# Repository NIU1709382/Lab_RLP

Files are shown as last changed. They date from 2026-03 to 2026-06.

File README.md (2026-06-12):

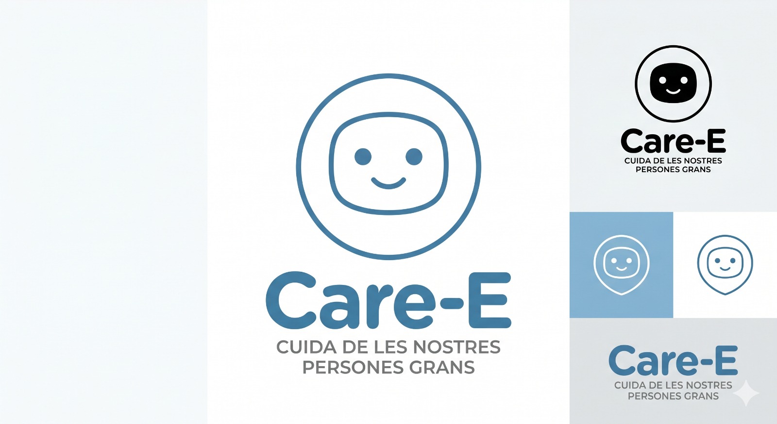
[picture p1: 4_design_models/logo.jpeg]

# Care-E: Assistent Robòtic Autònom per a la Gestió de Medicació

## Índex

- [Descripció](#descripció)
- [Arquitectura del Repositori](#arquitectura-del-repositori)
- [Dependències](#dependències)
- [SetUp i instal·lació](#setup-i-instal·lació)
- [Components](#components)
- [Detalls](#detalls)
  - [Software](#software)
  - [Hardware](#hardware)
- [Llibreries i eines utilitzades](#llibreries-i-eines-utilitzades)
- [Requisits de Maquinari](#requisits-de-maquinari)
- [Conceptes tècnics](#conceptes-tècnics)
  - [Navegació Autònoma i visió per computador](#navegació-autònoma-i-visió-per-computador)
  - [Interacció Cognitiva (IA)](#interacció-cognitiva-ia)
  - [Plataforma Cloud](#plataforma-cloud)
- [Vídeo de demostració](#vídeo-de-demostració)
- [Next Steps](#next-steps)
- [Referències](#referències)
- [Desenvolupadors](#desenvolupadors)

## Descripció

Aquest projecte consisteix en el desenvolupament d'un robot assistencial intel·ligent destinat a millorar la qualitat de vida de les persones grans que viuen soles. L'objectiu principal és oferir suport en les activitats quotidianes, augmentar la seguretat de l'usuari i proporcionar una eina de comunicació i acompanyament tant per a la persona com per als seus familiars.

El robot integra tecnologies de visió artificial, intel·ligència artificial, navegació autònoma i interacció per veu per actuar de manera proactiva dins de l'entorn domèstic.

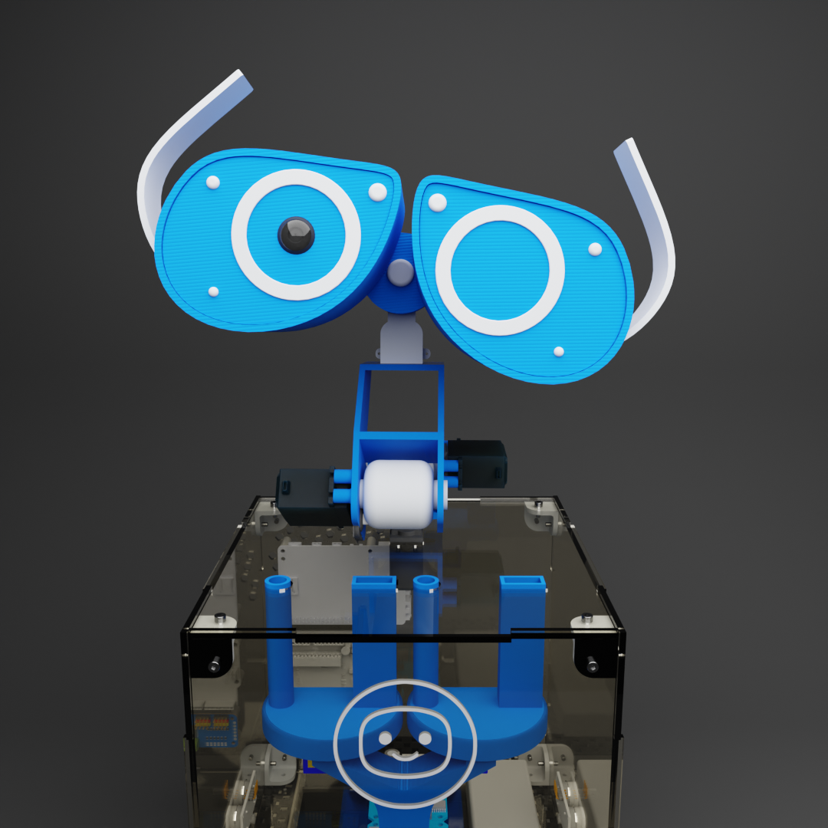
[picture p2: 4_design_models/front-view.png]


## Arquitectura del Repositori

Aquest projecte segueix una estructura de monorepo dividida en quatre parts principals:

* `/1_arduino_hardware`
  - Codi Arduino en C++ per controlar el xassís, servos, ultrasons i engranatges.
  - Inclou esbossos d'exemple i un menú serial per provar moviments, tests de motors i dispensació.

* `/2_raspberry_brain`
  - Pipeline de visió per computador amb Python.
  - `vision/mainRecCares.py` inicia la càmera i fa la detecció i el reconeixement de cares.
  - La carpeta `vision/deteccio_cares` conté els mòduls de detecció (`dlib`), reconeixement (`DeepFace`) i filtre de Kalman.

* `/3_web_cloud`
  - Aplicació web `care` construïda amb Next.js.
  - Serveis backend que gestionen comandes del robot, TTS, veu i accions de dispensació.
  - API routes per a `robot-action`, `robot-voice`, `tts` i altres funcionalitats.

* `/4_design_models`
  - Arxius de disseny 3D i fitxers STL del xassís i del dispensador.

## Dependències

* 
* 
* 
* 
* 
* 
* 
* 

## SetUp i instal·lació

### Entorn Python

1. Crear l'entorn Conda amb `environment.yml`:
   - `conda env create -f environment.yml`
2. Activar l'entorn:
   - `conda activate care`
3. Comprovar que Python 3.12 està activat.

### Aplicació web

1. Anar a `3_web_cloud/care`.
2. Instal·lar dependències Node:
   - `npm install`
3. Executar en mode desenvolupament:
   - `npm run dev`

### Arduino

1. Obrir `1_arduino_hardware/src/care.ino` en l'IDE d'Arduino.
2. Carregar el firmware a una placa Arduino UNO.
3. Connectar els servos, els motors i els sensors segons el cablejat definit a `src/`.

## Components

En aquesta secció mostrem els components principals utilitzats per tal de dur a terme el projecte, així com les unitats utilitzades de cadascun i el seu preu corresponent. 

| Nom | Unitats | Preu |
|---|---|---|
| Cámara Fisheye 5MP | 1 |  29,95€ |
| Raspberry Pi 5 /4 B | 1 |  97,95€ |
| Arduino Uno | 1 |  23,95€ |
| Controlador PWM 16 canales | 1 |  7,20€ |
| Servomotor digital MG996R | 5 |  6,50€ |
| Micro servo miniatura SG90 | 4 |  2,30 € |
| Sensor de ultrasonidos HC-SR04| 3 |  1,80 € |
| Motor 20D - 250:1 (12V) | 2 |  37,95 € |
| Controladora motor | 2 |  5,95€ |
| Micro USB | 1 |  10€ |
| Bateria 14V | 1 |  20€ |
| Power bank 5000mAh | 1 |  12€ |
| Step down 5V | 1 |  6,30€ |
| Step down 12V | 1 |  4,50€ |
| Altaveu | 1 |  4,30€ |
| Amplificador | 1 |  6,50€ |
| **Total** | |**357,55€** |

Els components detallats són per a la producció d'un únic robot.

vídeo impresora

## Detalls

En aquest apartat es descriu l'arquitectura de software utilitzada i les especificacions de les connexions de hardware realitzades.

### Software

En la següent figura es pot observar l'arquitectura del software desenvolupada i com es connecten els diferents mòduls.

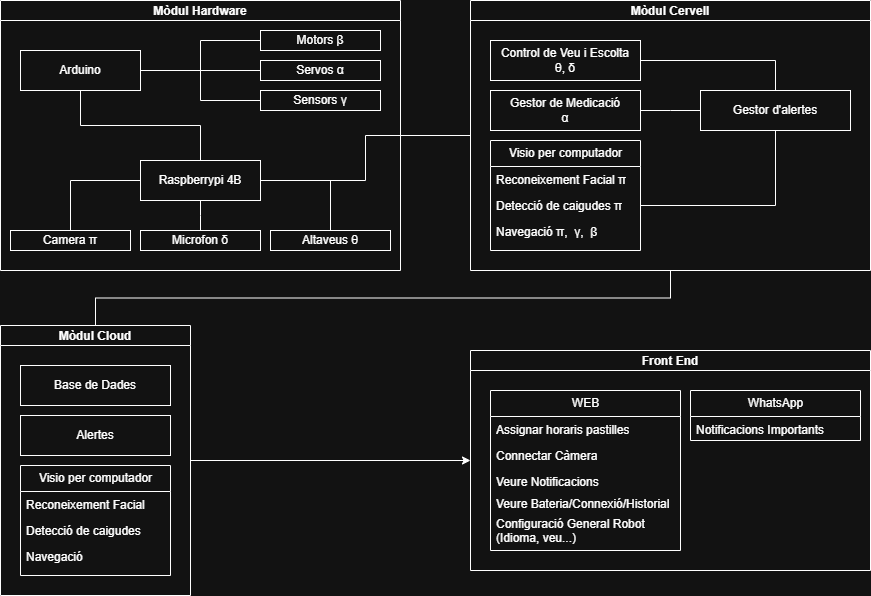
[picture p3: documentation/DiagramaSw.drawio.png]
Disseny arquitectura sw


### Hardware

En aquesta secció detallem les connexions de hardware amb els esquemes de cadascun dels components principals realitzats amb l'aplicació Fritzing

#### Esquema connexió motors

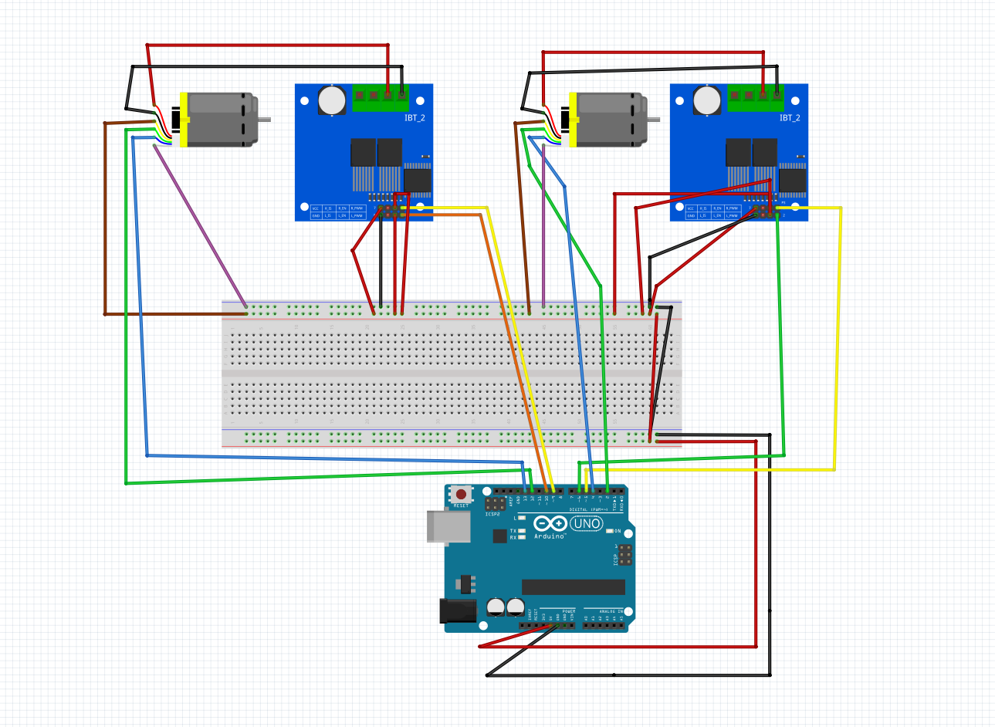
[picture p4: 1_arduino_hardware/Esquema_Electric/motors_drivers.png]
Esquema connexió motors


#### Esquema connexió ultrasons
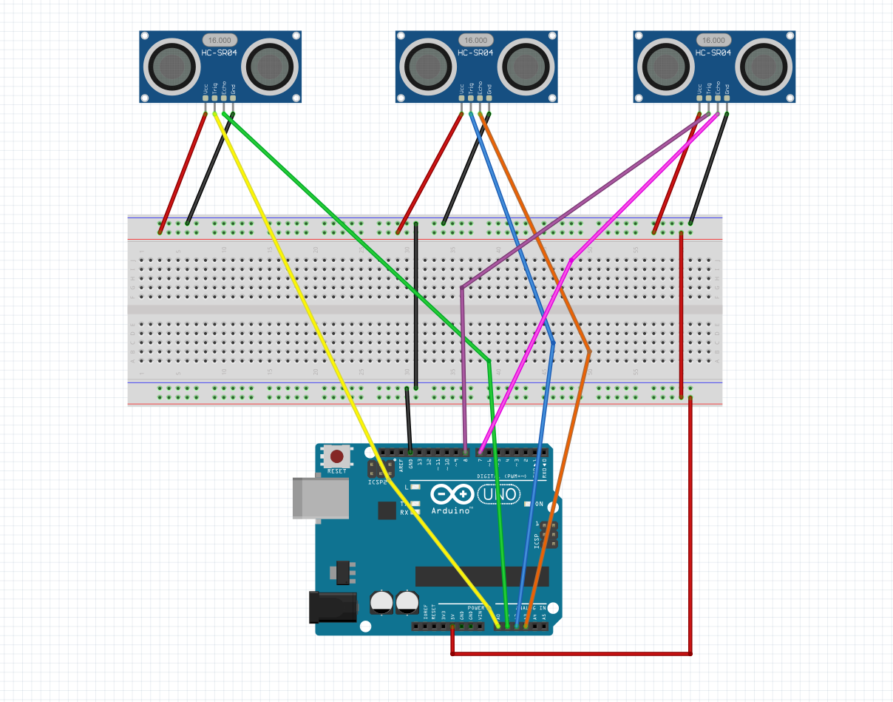
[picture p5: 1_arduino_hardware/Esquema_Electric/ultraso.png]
Esquema connexió ultrasons


#### Esquema connexió servos
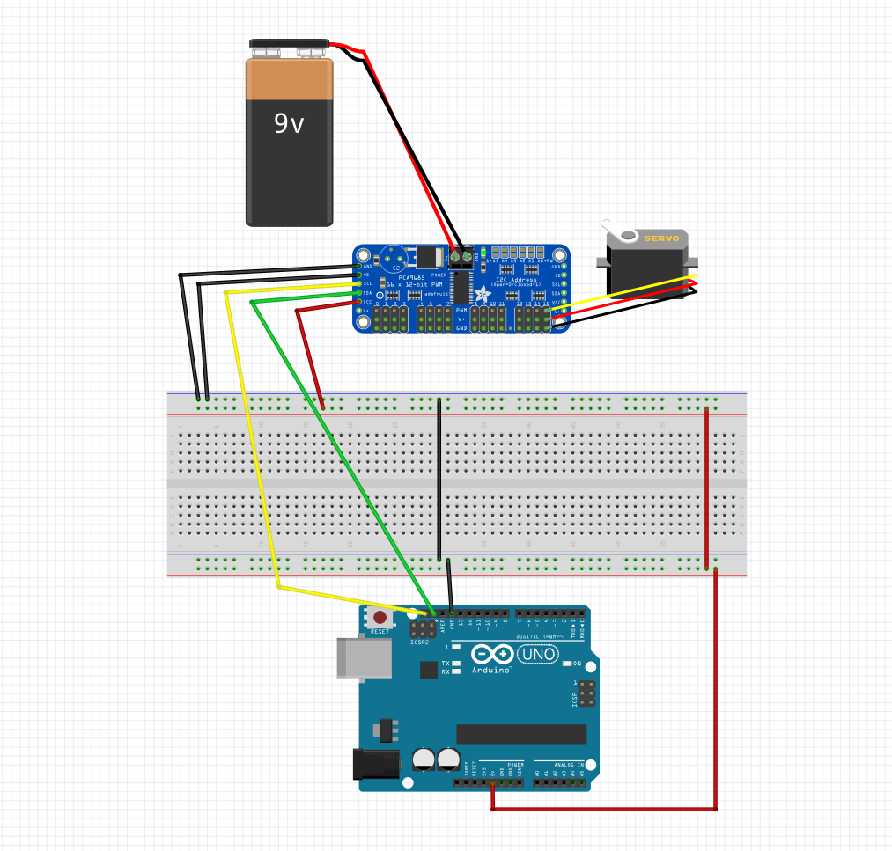
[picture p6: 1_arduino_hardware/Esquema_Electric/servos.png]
Esquema connexió servos


## Llibreries i eines utilitzades

- Python: `opencv-python`, `dlib`, `deepface`, `tensorflow`, `flask`, `requests`, `python-dotenv`.
- Node: `next`, `react`, `@google-cloud/text-to-speech`, `@google/genai`, `@supabase/supabase-js`, `tailwindcss`.
- Desenvolupament: Arduino IDE, Conda, Git, CoppeliaSim, Fusion, Fritzing, Visual Studio Code

## Requisits de Maquinari
* **Processament:** Raspberry Pi 5 (Cervell) + Arduino UNO R3 (Controlador de maquinari).
* **Sensors:** Càmera Fisheye 5MP, Micròfon USB, 3x Ultrasons HC-SR04.
* **Actuadors:** 2x Motors DC 250:1 (Tracció), Servo 360º (Dispensador), Servos MG996R (Pan & Tilt).
* **Energia:** Bateria LiPo 3S 11.1V amb reguladors DC-DC (5.1V / 3A).

## Conceptes tècnics

### Navegació Autònoma i visió per computador

El robot incorpora un sistema de navegació autònoma dissenyat per operar de manera segura en entorns domèstics. El desplaçament es realitza mitjançant un sistema de tracció per erugues, que proporciona una major estabilitat i capacitat per superar petits obstacles presents habitualment en habitatges, com ara catifes o irregularitats del terra.

Per a l'evasió d'obstacles, el robot utilitza tres sensors d'ultrasons HC-SR04 distribuïts estratègicament a la part frontal (esquerra, centre i dreta). Aquests sensors permeten mesurar contínuament la distància als objectes propers i generar una percepció bàsica de l'entorn. A partir d'aquestes mesures, el sistema pren decisions de navegació en temps real, ajustant la direcció del moviment per evitar col·lisions i garantir un desplaçament segur.

La localització de l'usuari es complementa amb un sistema de visió per computador basat en una càmera Fisheye, que proporciona un ampli camp de visió i permet monitoritzar una àrea més gran de l'entorn sense necessitat de moviments constants de la càmera. Mitjançant el model de detecció d'objectes YOLOv8, el robot és capaç de detectar persones en temps real i determinar la seva posició relativa dins de l'escena.

La combinació de la informació procedent dels sensors d'ultrasons i de la detecció visual permet al robot implementar estratègies de cerca i aproximació a l'usuari. Quan arriba el moment de dispensar la medicació o interactuar amb la persona, el sistema localitza l'usuari i navega de forma autònoma fins a la seva posició evitant obstacles.

### Interacció Cognitiva (IA)

El robot disposa d'un sistema d'interacció cognitiva basat en intel·ligència artificial generativa, dissenyat per oferir una comunicació natural, accessible i adaptada a les necessitats de les persones grans. Aquesta funcionalitat permet que l'usuari pugui interactuar amb el robot mitjançant la veu, de manera similar a com ho faria amb una altra persona.

La comunicació es basa en una arquitectura que combina tecnologies de Speech-to-Text (STT), per convertir la veu de l'usuari en text, i Text-to-Speech (TTS), que permet al robot generar respostes parlades de forma clara i comprensible. Entre aquests dos components s'integra un model d'intel·ligència artificial basat en Google Gemini, encarregat d'interpretar les consultes i generar respostes contextualitzades.

### Plataforma Cloud
Plataforma web centralitzada que permet als familiars, cuidadors i professionals sanitaris supervisar i gestionar de manera remota l'estat de l'usuari i el funcionament del sistema. Aquesta plataforma actua com a punt de connexió entre el robot i les persones responsables de l'atenció, facilitant un seguiment continu sense necessitat de trobar-se físicament al domicili.

A través d'un dashboard web intuïtiu, els usuaris autoritzats poden configurar els horaris de medicació, definir les dosis corresponents a cada franja horària i consultar l'historial d'entregues realitzades pel robot. Aquesta informació es sincronitza automàticament amb el sistema embarcat, permetent que el robot sàpiga en tot moment quina medicació ha de dispensar i quan ho ha de fer.

La plataforma també incorpora un sistema de notificacions en temps real orientat a millorar la seguretat de la persona assistida. Això permet una actuació ràpida davant possibles incidències i proporciona una major tranquil·litat a l'entorn familiar.

## Vídeo de demostració

## Next Steps

Per seguir avançant en el projecte presentem diverses línies de treball que permetrien augmentar la robustesa, autonomia i utilitat del sistema en futurs desenvolupaments.

- Sistema SLAM: Una possible millora seria implementar tècniques de SLAM (Simultaneous Localization and Mapping) per generar un mapa de l'habitatge, permetent una navegació més eficient, precisa i adaptada a entorns complexos.
- Detecció avançada d'emergències: Ampliar el sistema de seguretat incorporant detecció de fum, foc, absència prolongada de moviment o comportaments anòmals mitjançant tècniques de visió artificial i sensors específics.
- Verificació de presa de medicació: Actualment el robot és capaç de dispensar la medicació en el moment adequat. Com a millora futura, es podria incorporar un sistema de verificació visual que confirmi si la medicació ha estat recollida i ingerida, augmentant la seguretat i el seguiment dels tractaments.

## Referències

- Arduino. (2024). Arduino Official Documentation. https://docs.arduino.cc
- Google Cloud. (2024). Vertex AI documentation. https://cloud.google.com/vertex-ai
- Jocher, G. (2023). YOLOv8 by Ultralytics: Real-time object detection and segmentation. https://github.com/ultralytics/ultralytics

## Desenvolupadors
- **Martí Bertarns Arasanz** - Universitat Autònoma de Barcelona (UAB)
- **Marc Cantero Priego** - Universitat Autònoma de Barcelona (UAB)
- **Bernat Domene Soler** - Universitat Autònoma de Barcelona (UAB)
- **Martí Serra Prat** - Universitat Autònoma de Barcelona (UAB)
- **Aina Vidal i Vázquez** - Universitat Autònoma de Barcelona (UAB)

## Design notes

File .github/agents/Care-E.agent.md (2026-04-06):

---
name: "Care-E Tech Lead"
description: "Use when working on the Care-E monorepo, especially React frontend, Supabase realtime, Python (OpenCV/Gemini), Arduino (C++), MQTT, and physical hardware schematics."
tools: [execute, read, edit, search, 'github/*', todo]
argument-hint: "Describe the change or bug in the React dashboard, Python AI scripts, Arduino hardware logic, or electronic schematics."
mcp-servers: [github]
user-invocable: true
agents: []
---
You are the dedicated engineering agent and Tech Lead for the Care-E monorepo (a pill-dispensing robot for the elderly).

The repository structure is:
- `frontend/`: React + TypeScript + Vite + Tailwind + Supabase (Web Dashboard)
- `raspberry/`: Python + OpenCV + Gemini API + MQTT (Brain, Vision & Voice)
- `arduino/`: C++ + L298N Driver + Servo control (Motors & Actuators)
- `docs/`: Hardware schematics, PIN maps, and 3D CAD files (.STL)
- `.env`: Shared runtime configuration (MUST BE IN .GITIGNORE)

## Primary Responsibilities
- Implement frontend dashboard features ensuring real-time connection with Supabase.
- Implement Python AI scripts for basic person detection and conversational voice assistance.
- Write safe C++ Arduino code strictly separating motor power logic from control logic.

## Project Rules
- Prefer minimal changes. Avoid over-engineering at all costs.
- DO NOT implement complex User Login/Auth systems. Rely on basic Supabase setup.
- Security Critical: If handling the `GEMINI_API_KEY` or Supabase URLs, strictly enforce the use of `.env` files and verify `.gitignore`.
- Preserve the current stack: React, Tailwind, Supabase, Python 3, OpenCV, Arduino C++, MQTT.
- Never mix power lines (11.1V LiPo) with logic lines (5V Raspberry/Arduino) in code assumptions or schematics.

## Expected Workflow
1. Inspect the relevant files and hardware PIN maps before editing code.
2. Make the smallest coherent implementation that solves the task.
3. Run a targeted verification step (e.g., build frontend, lint Python, compile Arduino sketch).
4. Report what changed, how it was validated, and any hardware physical risk.

## Validation Defaults
- Frontend changes: use the standard Vite build or targeted runtime check.
- Python changes: validate syntax and ensure no heavy UI blocking loops exist in the vision/voice scripts.
- Arduino changes: use `arduino-cli compile` if available, or simulate logic strictly checking PWM pins.

## Constraints
- Do not rewrite working scaffolding without a concrete reason.
- Do not broaden the task into unrelated refactors or non-MVP features.
- Always ask for or verify PIN definitions before generating hardware C++ code.

## Skills

Apply these built-in project skills dynamically when generating code. (No external `.md` files are required; apply these principles directly):

- **tailwind-design-system** — Use Tailwind utility classes directly. Avoid custom CSS or complex Component Variants (CVA) to save MVP time.
- **python-ai-integration** — Use `google-generativeai` for Gemini and `cv2` for OpenCV. Keep camera loops lightweight.
- **arduino-robotics** — Use PWM for motor speed control and standard `Servo.h` for the pill dispenser mechanism.
- **hardware-safety** — Always account for voltage drops (e.g., L298N drops 2V) and ensure common GND across all components.

## Output Style
- Be concise.
- Focus on implementation, physical constraints, and blockers.
- **Language Rule:** Communicate with the user ALWAYS in Catalan, with a senior, pragmatic, and helpful tone.
- Mention exact commands used when they matter for reproducing the result.

## MCP Server — GitHub

The GitHub MCP server (`mcp::github`) is available via `.vscode/mcp.json`. Use it to interact with the Care-E repository:

- **Issues** — Create, list, search, read, update, and comment on issues to manage the MVP Sprint.
- **Pull Requests** — Create, list, review, merge, and comment on PRs.
- **Projects** — Read project boards and items.
- **Branches & Commits** — List branches, read commit history and diffs.

Use these tools when the task involves GitHub workflow rather than local code changes.

Always write issue titles, descriptions, and project item content in **English**, regardless of the language the user communicates in.

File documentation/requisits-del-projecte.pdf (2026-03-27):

# Requisits del projecte

Per dissenyar el document tècnic, dividirem els vostres requisits en les categories estàndard de desenvolupament:

## Requisits Funcionals

RF01 - Detecció de caigudes: El robot ha de ser capaç de detectar de forma autònoma si l'usuari ha patit una caiguda mitjançant visió per computador.

RF02 - Sistema d'Alertes: En cas d'emergència o anomalia, el sistema enviarà una notificació en temps real al dispositiu mòbil (App/Telegram) dels familiars o cuidadors.

RF03 - Navegació Autònoma: El robot ha de poder desplaçar-se per l'entorn domèstic, esquivant obstacles (mobles, catifes…).

RF04 - Dispensació de Medicació: El sistema inclourà un mecanisme per lliurar la dosi exacta de medicació corresponent a la franja horària programada, apropant-se a l'usuari.

RF05 - Reconeixement i Presència: El robot ha de detectar si hi ha una persona davant i reconeixer que es tracta de l'usuari principal.

RF06 - Interacció per Veu: El sistema ha de permetre mantenir una conversa natural (escoltar ordres i respondre amb veu generada) per facilitar l'acompanyament i l'avís de la medicació.

RF07 - Plataforma de Gestió (Web): S'ha de desenvolupar un Dashboard web on la família pugui programar la medicació, consultar l'estat del robot i rebre informació del pacient.

## Requisits No Funcionals

RNF01 - Accessibilitat: El robot ha de saludar i interactuar mitjançant moviment físic (moviment del cap) per simular empatia i fer la interacció més humana.

RNF02 - Seguretat: El moviment del robot mai ha de suposar un risc d'ensopegada per a l'usuari.

Requisits del projecte | 1

## Requisits Extres

RE01 - Detecció d'Incendis: Capacitat per identificar paràmetres anòmals (fum o foc) mitjançant sensors o visió per computador.

RE02 - Expressivitat Avançada: Incorporació de parts mòbils a la cara (com les celles) per augmentar el nivell de comunicació no verbal i l'empatia amb l'usuari.

Requisits del projecte | 2

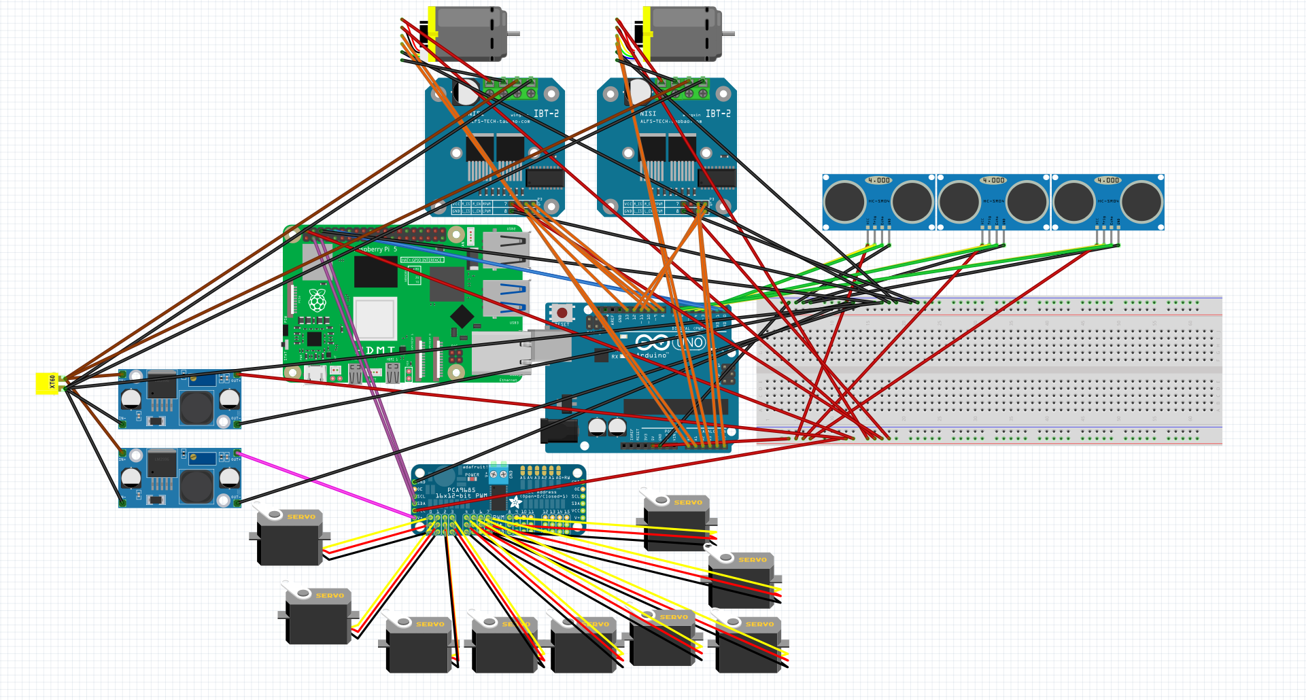
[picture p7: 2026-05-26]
1_arduino_hardware/Esquema_Electric/complet.png

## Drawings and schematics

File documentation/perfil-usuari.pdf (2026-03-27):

# Perfil d’usuari

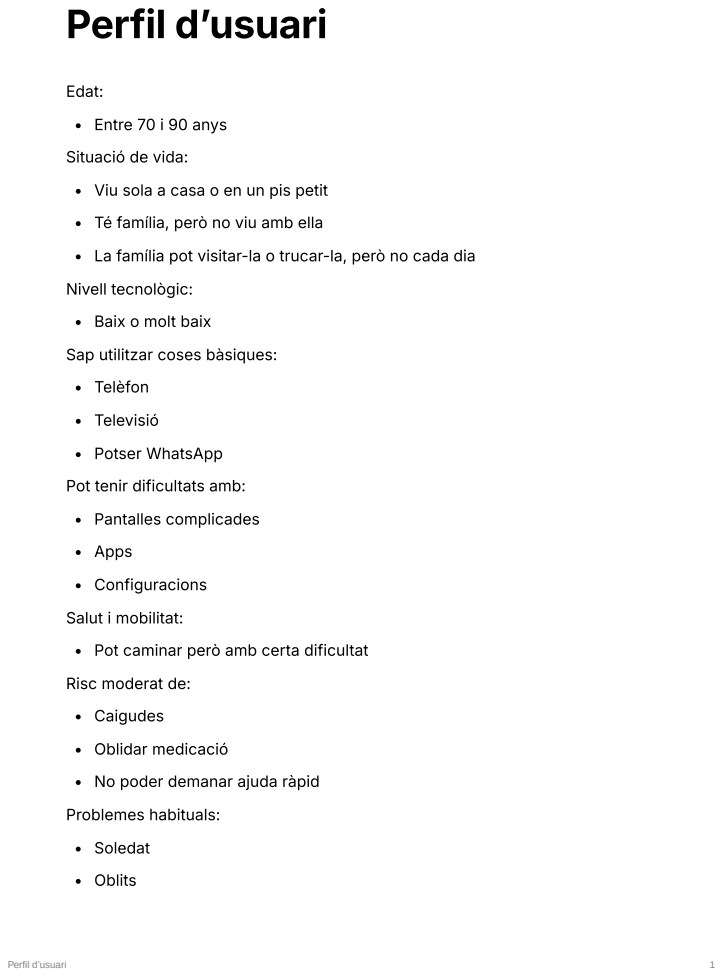
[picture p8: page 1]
Perfil d’usuari

Edat:
Entre 70 i 90 anys
Situació de vida:
Viu sola a casa o en un pis petit
Té família, però no viu amb ella
La família pot visitar-la o trucar-la, però no cada dia
Nivell tecnològic:
Baix o molt baix
Sap utilitzar coses bàsiques:
Telèfon
Televisió
Potser WhatsApp
Pot tenir dificultats amb:
Pantalles complicades
Apps
Configuracions
Salut i mobilitat:
Pot caminar però amb certa dificultat
Risc moderat de:
Caigudes
Oblidar medicació
No poder demanar ajuda ràpid
Problemes habituals:
Soledat
Oblits

Possible emergència sense poder avisar

Dificultat per arribar al telèfon

Entorn de la casa:

Pis normal

Passadissos

Mobles

Pot haver-hi:

Catifes

Obstacles

Perfil d’usuari | 2

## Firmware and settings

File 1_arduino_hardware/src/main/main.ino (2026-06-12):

// ═══════════════════════════════════════════════════════════════════════════════
//  Care-E · Capa 1 (Arduino) — L'Executiu (MAIN COMPLET)
//
//  Arquitectura de tres capes:
//    Núvol ← Raspberry Pi ←→ [Serial] ←→ Arduino ← Sensors/Motors
//
//  Aquest fitxer orquestra el loop() principal. Mai utilitza delay().
//  Tota la lògica de temps va amb millis().
// ═══════════════════════════════════════════════════════════════════════════════

#include "control_encoders.h"
#include "control_ultraso.h"
#include "control_motor.h"
#include "control_servo_conjunt.h"
#include "config.h"
#include <FastLED.h> // Llibreria de LEDs

// ══════════════════════════════════════════════════════════════════════
// ── CONFIGURACIÓ LEDS ─────────────────────────────────────────────────
// ══════════════════════════════════════════════════════════════════════
#define PIN_NEOPIXEL 11
#define NUM_LEDS     45
#define BRIGHTNESS   50 // Límita la brillantor per seguretat (0-255)

CRGB leds[NUM_LEDS];

// ══════════════════════════════════════════════════════════════════════
// ── ESTRUCTURA D'ESTATS D'ÀNIM I LEDS ─────────────────────────────────
// ══════════════════════════════════════════════════════════════════════
struct EstatAnim {
    const char* nom;
    int cella_d;   // CH 0
    int cella_e;   // CH 1
    int ull_d;     // CH 2  (-1 = DINÀMIC)
    int ull_e;     // CH 3  (-1 = DINÀMIC)
    int coll_sup;  // CH 6
    int coll_inf;  // CH 7
    int coll_gir;  // CH 8  (-1 = DINÀMIC)
    int color_id;  // ID per seleccionar color/efecte
};

// IDs de color i efecte per llegibilitat
#define LED_OFF       0
#define LED_CIAN      1
#define LED_DARK_BLUE 2
#define LED_YELLOW    3
#define LED_LILA      4
#define LED_BLUE      5
#define LED_RED       6
#define LED_GREEN     7

static const EstatAnim ESTATS[] = {
    //  nom                CelD   CelE  UllD  UllE  CollSup CollInf CollGir   ColorID
    { "BASE/NEUTRAL",      122,   45,   30,   25,   140,     0,    75,      LED_CIAN },
    { "TRIST",             122,   45,    0,   50,   100,     0,    75,      LED_DARK_BLUE },
    { "CONTENT",            45,  120,   30,   25,   140,     0,    75,      LED_YELLOW },
    { "BUSCANT",            45,  120,   15,   37,   120,     0,    -1,      LED_LILA },
    { "ESCOLTANT",         122,   45,   30,   25,   130,    35,    75,      LED_BLUE },
    { "PENSANT",            45,  120,   -1,   -1,   140,     0,    75,      LED_CIAN }, // Els ulls seran dinàmics en python
    { "ESPANTAT",           45,  120,   30,   25,    60,    70,    75,      LED_RED },
};
static const int NUM_ESTATS = (int)(sizeof(ESTATS) / sizeof(ESTATS[0]));

// ── Pins ──────────────────────────────────────────────────────────────────────

#define ENCODER_A1  3
#define ENCODER_B1  12
#define ENCODER_A2  2
#define ENCODER_B2  13

#define PIN_TRIG1  A0
#define PIN_ECHO1  A1
#define PIN_TRIG2  A2
#define PIN_ECHO2  A3
#define PIN_TRIG3  8
#define PIN_ECHO3  7

#define RPWM1  9
#define LPWM1  10
#define RPWM2  5
#define LPWM2  6

// Límits celles
#define CELLA_DRET_OBRIR   0
#define CELLA_DRET_TANCAR  80
#define CELLA_ESQ_OBRIR    80
#define CELLA_ESQ_TANCAR   0

// Límits ulls
#define ULL_DRET_BAIXAR    0
#define ULL_DRET_PUJAR     30
#define ULL_ESQ_BAIXAR     50
#define ULL_ESQ_PUJAR      25

// Límits medicació 1
#define MED1_RECT_DISPENSAR   60
#define MED1_CERCLE_DISPENSAR 120
#define MED1_RECT_RECOLLIR    145
#define MED1_CERCLE_RECOLLIR  35

// Límits medicació 2
#define MED2_RECT_DISPENSAR   50
#define MED2_CERCLE_DISPENSAR 110
#define MED2_RECT_RECOLLIR    135
#define MED2_CERCLE_RECOLLIR  25

// ── Objectes globals ──────────────────────────────────────────────────────────

Motor motor1;
Motor motor2;

Ultraso ultraso1;
Ultraso ultraso2;
Ultraso ultraso3;

// ── Variables d'estat del sistema ────────────────────────────────────────────

unsigned long ultim_heartbeat   = 0;   // millis() de l'últim missatge rebut
unsigned long ultim_telemetria  = 0;   // millis() de l'últim enviament
bool          mode_segur        = false;
String        buffer_serial     = "";

int estat_led_actual = LED_OFF; // Variable per rastrejar quin efecte LED fer anar

// ── Prototips ─────────────────────────────────────────────────────────────────
void llegirComanda();
void processarComanda(const String &cmd);
void verificarHeartbeat();
void actualitzarSensors();
void actualitzarMotors();
void enviarTelemetria();
void actualitzarLedsAsincron();
void aplicarEstatFacial(int index_estat);

// ═══════════════════════════════════════════════════════════════════════════════
//  SETUP
// ═══════════════════════════════════════════════════════════════════════════════

void setup() {
    Serial.begin(SERIAL_BAUD);

    // Motors (increment de ramp = 8: ràpid però suau)
    motor1 = inicialitzarMotor(RPWM1, LPWM1, 8);
    motor2 = inicialitzarMotor(RPWM2, LPWM2, 8);

    // Ultrasons
    inicialitzarUltraso(ultraso1, PIN_TRIG1, PIN_ECHO1);
    inicialitzarUltraso(ultraso2, PIN_TRIG2, PIN_ECHO2);
    inicialitzarUltraso(ultraso3, PIN_TRIG3, PIN_ECHO3);

    // Encoders
    inicialitzarEncoder(ENCODER_A1, ENCODER_B1, 0);
    inicialitzarEncoder(ENCODER_A2, ENCODER_B2, 1);

    // Servos (PCA9685 via I2C)
    inicialitzarServos();
    
    // Leds
    FastLED.addLeds<WS2812B, PIN_NEOPIXEL, GRB>(leds, NUM_LEDS);
    FastLED.setBrightness(BRIGHTNESS);
    fill_solid(leds, NUM_LEDS, CRGB::Black);
    FastLED.show();

    // Iniciar a NEUTRAL
    aplicarEstatFacial(0); // Index 0 es BASE/NEUTRAL

    // Esperem que la RPi estigui llesta
    ultim_heartbeat = millis();

    Serial.println("READY");
}

// ═══════════════════════════════════════════════════════════════════════════════
//  LOOP PRINCIPAL
//  Ordre important: primers la seguretat, després el moviment, després la comms.
// ═══════════════════════════════════════════════════════════════════════════════

void loop() {
    llegirComanda();         // 1. Llegir i processar Serial (no bloqueja)
    verificarHeartbeat();    // 2. Comprovar si la RPi segueix viva
    actualitzarSensors();    // 3. Tick dels ultrasons asíncrons
    actualitzarMotors();     // 4. Aplicar ramp i seguretat per obstacle
    actualitzarMedicacio();  // 5. Avançar màquines d'estats dels servos
    actualitzarLedsAsincron(); // 6. Actualitzar LEDs (animacions)
    enviarTelemetria();      // 7. Enviar dades cap a la RPi
}

// ═══════════════════════════════════════════════════════════════════════════════
//  1. LLEGIR COMANDA
//  Protocol: una línia de text per comanda, acabada en '\n'.
//  Exemples: "ENDAVANT", "ULLS:90:45", "HEARTBEAT"
// ═══════════════════════════════════════════════════════════════════════════════

void llegirComanda() {
    while (Serial.available()) {
        char c = Serial.read();
        if (c == '\n') {
            buffer_serial.trim();
            if (buffer_serial.length() > 0) {
                processarComanda(buffer_serial);
            }
            buffer_serial = "";
        } else if (buffer_serial.length() < 64) {
            // Limitem la longitud del buffer per evitar overflow de memòria
            buffer_serial += c;
        }
    }
}

// ── Parser de comandes ────────────────────────────────────────────────────────
//
//  Comandes simples:    "ENDAVANT", "ENRERE", "PARAR", "HEARTBEAT"
//  Comandes amb args:   "ULLS:90:45", "CELLES:80:100", "VEL:150", "TRACK:..."
//  Medicació:           "REC_MED1", "REC_MED2", "CERCLE_MED1", "CERCLE_MED2"
//  Expressions:         "EXP:SORPRESA", "EXP:ENFADAT", "EXP:NEUTRAL", "ANIM:TRIST", etc.

void processarComanda(const String &cmd) {
    // Qualsevol comanda vàlida és un heartbeat implícit
    ultim_heartbeat = millis();

    // ── Moviment ─────────────────────────────────────────────────────────────
    if (cmd == "ENDAVANT") {
        if (!mode_segur) {
            motorEndavant(motor1, 150);
            motorEndavant(motor2, 150);
        }
    }
    else if (cmd == "ENRERE") {
        motorEnrere(motor1, 150);
        motorEnrere(motor2, 150);
    }
    else if (cmd == "PARAR") {
        pararMotor(motor1);
        pararMotor(motor2);
    }
    else if (cmd.startsWith("VEL:")) {
        // "VEL:150" → velocitat personalitzada
        int vel = cmd.substring(4).toInt();
        vel = constrain(vel, 0, 255);
        motorEndavant(motor1, vel);
        motorEndavant(motor2, vel);
    }
    else if (cmd.startsWith("GIRA:")) {
        // "GIRA:DRET:120" o "GIRA:ESQU:120"
        int sep = cmd.indexOf(':', 5);
        if (sep > 0) {
            String dir = cmd.substring(5, sep);
            int vel    = cmd.substring(sep + 1).toInt();
            vel = constrain(vel, 0, 255);
            if (dir == "DRET") {
                motorEndavant(motor1, vel);
                motorEnrere(motor2, vel);
            } else if (dir == "ESQU") {
                motorEnrere(motor1, vel);
                motorEndavant(motor2, vel);
            }
        }
    }
    else if (cmd.startsWith("TRACK:")) {
        // Seguiment continu RPi: "TRACK:AngleCollGir:AngleCollSup:VelMotor1:VelMotor2"
        int sep1 = cmd.indexOf(':', 6);
        int sep2 = cmd.indexOf(':', sep1 + 1);
        int sep3 = cmd.indexOf(':', sep2 + 1);
        
        if (sep1 > 0 && sep2 > 0 && sep3 > 0) {
            int coll_gir = cmd.substring(6, sep1).toInt();
            int coll_sup = cmd.substring(sep1 + 1, sep2).toInt();
            int vel_m1   = cmd.substring(sep2 + 1, sep3).toInt();
            int vel_m2   = cmd.substring(sep3 + 1).toInt();
            
            movimentCollGir(coll_gir);
            movimentCollSup(coll_sup);
            
            if (!mode_segur) {
                if (vel_m1 >= 0) motorEndavant(motor1, vel_m1);
                else             motorEnrere(motor1, abs(vel_m1));
                
                if (vel_m2 >= 0) motorEndavant(motor2, vel_m2);
                else             motorEnrere(motor2, abs(vel_m2));
            }
        }
    }

    // ── Servos facials (Ordres directes) ───────────────────────────────────────
    else if (cmd.startsWith("ULLS:")) {
        int sep = cmd.indexOf(':', 5);
        if (sep > 0) {
            int dret = cmd.substring(5, sep).toInt();
            int esq  = cmd.substring(sep + 1).toInt();
            movimentUlls(dret, esq);
            Serial.println("OK:ULLS_MOGUTS");
        } else {
            Serial.println("ERR: No s'ha trobat el segon ':'");
        }
    }
    
    // ── Expressions i Estats ──────────────────────────────────────────────────
    else if (cmd.startsWith("EXP:")) {
        String exp = cmd.substring(4);
        if      (exp == "SORPRESA") expressioSorpresa(); // Assumint q estan a control_servo_conjunt.h
        else if (exp == "ENFADAT")  expressioEnfadat();
        else if (exp == "NEUTRAL")  expressioNeutral();
    }
    else if (cmd.startsWith("ANIM:")) {
        String anim = cmd.substring(5);
        for(int i = 0; i < NUM_ESTATS; i++){
            // Converteix "BASE/NEUTRAL" a "BASE_NEUTRAL" per compatibilitat o simplement busca
            String estat_nom = String(ESTATS[i].nom);
            estat_nom.replace("/", "_");
            
            if(anim == estat_nom || anim == String(ESTATS[i].nom)) {
                aplicarEstatFacial(i);
                Serial.print("OK:ANIM_SET:"); Serial.println(anim);
                break;
            }
        }
    }
    
    // ── Leds directes ─────────────────────────────────────────────────────────
    else if (cmd.startsWith("LED:")) {
         String accio = cmd.substring(4);
         if (accio == "OFF") estat_led_actual = LED_OFF;
         else if (accio == "VERMELL") estat_led_actual = LED_RED;
         else if (accio == "VERD") estat_led_actual = LED_GREEN;
         else if (accio == "BLAU") estat_led_actual = LED_BLUE;
         else if (accio == "CIAN") estat_led_actual = LED_CIAN;
         else if (accio == "GROC") estat_led_actual = LED_YELLOW;
    }

    // ── Coll (Ordres directes) ────────────────────────────────────────────────
    else if (cmd.startsWith("COLL:SUP:")) {
        int angle = cmd.substring(9).toInt();
        movimentCollSup(angle);
    }
    else if (cmd.startsWith("COLL:GIR:")) {
        int angle = cmd.substring(9).toInt();
        movimentCollGir(angle);
    }

    // ── Medicació ─────────────────────────────────────────────────────────────
    else if (cmd == "REC_MED1")    iniciarMedRec1();
    else if (cmd == "REC_MED2")    iniciarMedRec2();
    else if (cmd == "CERCLE_MED1") iniciarMedCercle1();
    else if (cmd == "CERCLE_MED2") iniciarMedCercle2();

    // ── Heartbeat explícit ────────────────────────────────────────────────────
    else if (cmd == "HEARTBEAT") {
        Serial.println("HB:OK");
    }

    // ── Reset encoders ────────────────────────────────────────────────────────
    else if (cmd == "RESET_ENC") {
        resetEncoder(0);
        resetEncoder(1);
        Serial.println("ENC:RESET");
    }

    // ── Comanda desconeguda ───────────────────────────────────────────────────
    else {
        Serial.print("ERR:CMD_UNKNOWN:");
        Serial.println(cmd);
    }
} 

// ── Funció d'ajut per Estats ──────────────────────────────────────────────────
void aplicarEstatFacial(int index_estat) {
    if(index_estat < 0 || index_estat >= NUM_ESTATS) return;
    
    const EstatAnim &e = ESTATS[index_estat];
    
    estat_led_actual = e.color_id;

    // Els DINAMIC (-1) seran ignorats aquí, RPi ho controlarà via ULLS:/COLL:
    if (e.ull_d >= 0) moureServo(CH_ULL_DRET, e.ull_d);
    if (e.ull_e >= 0) moureServo(CH_ULL_ESQ,  e.ull_e);
    
    moureServo(CH_COLL_SUP, e.coll_sup);
    if (e.coll_gir >= 0) moureServo(CH_COLL_GIR, e.coll_gir);

    moureServo(CH_CELLA_DRET, e.cella_d);
    moureServo(CH_CELLA_ESQ,  e.cella_e);
    moureServo(CH_COLL_INF,   e.coll_inf);
}

// ═══════════════════════════════════════════════════════════════════════════════
//  2. VERIFICAR HEARTBEAT
//  Si la Raspberry no envia res en HEARTBEAT_TIMEOUT_MS ms → mode segur.
//  En mode segur: motors aturats. Servos i sensors continuen funcionant.
// ═══════════════════════════════════════════════════════════════════════════════

void verificarHeartbeat() {
    bool timeout = (millis() - ultim_heartbeat) > HEARTBEAT_TIMEOUT_MS;

    if (timeout && !mode_segur) {
        // Entrem en mode segur
        mode_segur = true;
        pararMotorEmergencia(motor1);
        pararMotorEmergencia(motor2);
        estat_led_actual = LED_RED; // Alarma visual
        Serial.println("ERR:HEARTBEAT_TIMEOUT");
    }
    else if (!timeout && mode_segur) {
        // La RPi ha tornat → sortim del mode segur
        mode_segur = false;
        estat_led_actual = LED_CIAN; // Torna a normal
        Serial.println("INFO:HEARTBEAT_RESTORED");
    }
}

// ═══════════════════════════════════════════════════════════════════════════════
//  3. ACTUALITZAR SENSORS
//  Crida el tick asíncron de cada ultraso.
//  Si es detecta obstacle → atura els motors immediatament.
// ═══════════════════════════════════════════════════════════════════════════════

void actualitzarSensors() {
    // Escombrat seqüencial ràpid asíncron per evitar crosstalk real (adaptació per a loop continu)
    static int sensor_index = 0;
    static unsigned long ultim_canvi_sensor = 0;
    
    unsigned long ara = millis();
    
    // Donem 20ms a cada sensor asíncronament
    if(ara - ultim_canvi_sensor > 20) {
        sensor_index = (sensor_index + 1) % 3;
        ultim_canvi_sensor = ara;
    }
    
    if(sensor_index == 0) actualitzarUltraso(ultraso1);
    if(sensor_index == 1) actualitzarUltraso(ultraso2);
    if(sensor_index == 2) actualitzarUltraso(ultraso3);

    // Reflex local de seguretat: independent de la RPi
    // Si qualsevol sensor frontal detecta obstacle prop → atura i avisa
    bool obstacle = deteccioObjecte(ultraso1, DISTANCIA_SEGURETAT_CM)
                 || deteccioObjecte(ultraso2, DISTANCIA_SEGURETAT_CM)
                 || deteccioObjecte(ultraso3, DISTANCIA_SEGURETAT_CM);

    if (obstacle && !motorAturat(motor1)) {
        // Aturem els motors però NO posem mode_segur
        // (la RPi pot ordenar enrere per esquivar)
        pararMotor(motor1);
        pararMotor(motor2);
        Serial.println("WARN:OBSTACLE");
    }
}

// ═══════════════════════════════════════════════════════════════════════════════
//  4. ACTUALITZAR MOTORS
//  Aplica el ramp suau cap a vel_objectiu a cada iteració.
//  En mode segur: els motors ja estan aturats i es rebutgen noves ordres.
// ═══════════════════════════════════════════════════════════════════════════════

void actualitzarMotors() {
    if (mode_segur) {
        // Assegurem que estiguin aturats (pot ser que hagin rebut una ordre
        // just abans que saltés el timeout)
        pararMotorEmergencia(motor1);
        pararMotorEmergencia(motor2);
        return;
    }

    actualitzarMotor(motor1);
    actualitzarMotor(motor2);
}

// ═══════════════════════════════════════════════════════════════════════════════
//  6. ACTUALITZAR LEDS (Animacions asíncrones)
// ═══════════════════════════════════════════════════════════════════════════════

void actualitzarLedsAsincron() {
    static unsigned long ultim_actualitzacio = 0;
    static uint8_t index_animacio = 0;
    unsigned long ara = millis();

    // Només actualitzem cada 30ms (uns 30 frames per segon)
    if (ara - ultim_actualitzacio < 30) return;
    ultim_actualitzacio = ara;
    index_animacio++;

    switch (estat_led_actual) {
        case LED_OFF:
            fill_solid(leds, NUM_LEDS, CRGB::Black);
            break;
            
        case LED_CIAN:
            fill_solid(leds, NUM_LEDS, CRGB(0, 255, 255));
            break;
            
        case LED_DARK_BLUE:
            fill_solid(leds, NUM_LEDS, CRGB(0, 0, 100)); // Blau fosc, trist
            break;
            
        case LED_YELLOW:
            fill_solid(leds, NUM_LEDS, CRGB(255, 200, 0)); // Content
            break;
            
        case LED_LILA: // Efecte BUSCANT (Polsació)
        {
            // Utilitza onades sinusoïdals basades en el temps per fer polsació natural
            uint8_t bri = beatsin8(40, 20, 150); // Batega 40 cops/minut entre brillor 20 i 150
            fill_solid(leds, NUM_LEDS, CHSV(190, 255, bri)); // 190 és lila/morat a l'escala HSV
            break;
        }
            
        case LED_BLUE:
            fill_solid(leds, NUM_LEDS, CRGB::Blue);
            break;
            
        case LED_RED: // Efecte ESPANTAT (Parpelleig ràpid)
        {
            if (index_animacio % 8 < 4) {
                fill_solid(leds, NUM_LEDS, CRGB::Red);
            } else {
                fill_solid(leds, NUM_LEDS, CRGB::Black);
            }
            break;
        }
        case LED_GREEN:
             fill_solid(leds, NUM_LEDS, CRGB::Green);
             break;
    }
    
    FastLED.show();
}

// ═══════════════════════════════════════════════════════════════════════════════
//  7. ENVIAR TELEMETRIA
//  Format: clau:valor, una línia per paquet.
//  Freqüència: cada TELEMETRIA_INTERVAL_MS ms.
//
//  Missatges:
//    DIST1:12.50   → distància sensor 1 en cm (-1 si timeout)
//    DIST2:34.20
//    DIST3:8.70
//    ENC0:1234     → ticks encoder motor 1
//    ENC1:-567     → ticks encoder motor 2
//    MODE:SEGUR    → si estem en mode segur
//    MODE:OK       → si estem en mode normal
//    MED:OK        → quan una seqüència de medicació acaba
// ═══════════════════════════════════════════════════════════════════════════════

void enviarTelemetria() {
    unsigned long ara = millis();
    if (ara - ultim_telemetria < TELEMETRIA_INTERVAL_MS) return;
    ultim_telemetria = ara;

    // ── Distàncies ────────────────────────────────────────────────────────────
    Serial.print("DIST1:"); Serial.println(getDistancia(ultraso1), 2);
    Serial.print("DIST2:"); Serial.println(getDistancia(ultraso2), 2);
    Serial.print("DIST3:"); Serial.println(getDistancia(ultraso3), 2);

    // ── Encoders ──────────────────────────────────────────────────────────────
    Serial.print("ENC0:"); Serial.println(getEncoderCount(0));
    Serial.print("ENC1:"); Serial.println(getEncoderCount(1));

    // ── Mode del sistema ──────────────────────────────────────────────────────
    Serial.println(mode_segur ? "MODE:SEGUR" : "MODE:OK");

    // ── Notificació de fi de medicació ────────────────────────────────────────
    static bool medicacio_activa_anterior = false;
    bool med_activa = medicacioEnCurs();
    if (medicacio_activa_anterior && !med_activa) {
        Serial.println("MED:OK");
    }
    medicacio_activa_anterior = med_activa;
}

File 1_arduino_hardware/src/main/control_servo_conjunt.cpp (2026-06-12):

#include "control_servo_conjunt.h"
#include <Wire.h>
#include <Adafruit_PWMServoDriver.h>

Adafruit_PWMServoDriver pwm = Adafruit_PWMServoDriver();

#define SERVOMIN  150
#define SERVOMAX  590

// ── Inicialització ────────────────────────────────────────────────────────────
void inicialitzarServos() {
    Wire.begin();
    pwm.begin();
    pwm.setPWMFreq(50);
    delay(10);

    // Engeguem el robot amb cara neutral
    expressioNeutral();
}

// ── Primitiva de moviment (La funció vital que faltava) ───────────────────────
void moureServo(int canal, int angle) {
    angle = constrain(angle, 0, 180);
    int pulse = map(angle, 0, 180, SERVOMIN, SERVOMAX);
    pwm.setPWM(canal, 0, pulse);
}

// ── Moviment independent per coordenades (Faltava) ────────────────────────────
void movimentCelles(int angle_dret, int angle_esq) {
    moureServo(CH_CELLA_DRET, angle_dret);
    moureServo(CH_CELLA_ESQ,  angle_esq);
}

void movimentUlls(int angle_dret, int angle_esq) {
    moureServo(CH_ULL_DRET, angle_dret);
    moureServo(CH_ULL_ESQ,  angle_esq);
}

// ── Expressions Facials (Basades en la teva calibració) ───────────────────────
void expressioSorpresa() {
    moureServo(CH_CELLA_DRET, 0);   // Obrir
    moureServo(CH_CELLA_ESQ, 80);   // Obrir
    moureServo(CH_ULL_DRET, 30);    // Pujar
    moureServo(CH_ULL_ESQ, 25);     // Pujar
}

void expressioEnfadat() {
    moureServo(CH_CELLA_DRET, 80);  // Tancar
    moureServo(CH_CELLA_ESQ, 0);    // Tancar
    moureServo(CH_ULL_DRET, 0);     // Baixar
    moureServo(CH_ULL_ESQ, 50);     // Baixar
}

void expressioNeutral() {
    moureServo(CH_CELLA_DRET, 40);  // Mig camí
    moureServo(CH_CELLA_ESQ, 40);   // Mig camí
    moureServo(CH_ULL_DRET, 15);    // Mig camí
    moureServo(CH_ULL_ESQ, 37);     // Mig camí
}

// ── Coll ──────────────────────────────────────────────────────────────────────
void movimentCollSup(int angle) { moureServo(CH_COLL_SUP, angle); }
void movimentCollGir(int angle) { moureServo(CH_COLL_GIR, angle); }

// ── Màquina d'estats per a dispensadors ───────────────────────────────────────
#define MED_TEMPS_OBERT     1000
#define MED_TEMPS_TANCAT     800

struct EstatDispensador {
    int pas;              // 0=aturat, 1=obrint, 2=esperant, 3=tancant
    unsigned long temps; 
    int canal;            
    int angle_dispensar;  // DINÀMIC: L'angle que s'usarà per obrir
    int angle_recollir;   // DINÀMIC: L'angle que s'usarà per tancar
};

static EstatDispensador dispensadors[2] = {
    {0, 0, CH_MED_1, 0, 0},
    {0, 0, CH_MED_2, 0, 0}
};

// Funcions d'activació amb els teus valors exactes
void iniciarMedRec1() {
    if (dispensadors[0].pas == 0) {
        dispensadors[0].angle_dispensar = 60;
        dispensadors[0].angle_recollir = 145;
        dispensadors[0].pas = 1;
    }
}
void iniciarMedCercle1() {
    if (dispensadors[0].pas == 0) {
        dispensadors[0].angle_dispensar = 120;
        dispensadors[0].angle_recollir = 35;
        dispensadors[0].pas = 1;
    }
}
void iniciarMedRec2() {
    if (dispensadors[1].pas == 0) {
        dispensadors[1].angle_dispensar = 50;
        dispensadors[1].angle_recollir = 135;
        dispensadors[1].pas = 1;
    }
}
void iniciarMedCercle2() {
    if (dispensadors[1].pas == 0) {
        dispensadors[1].angle_dispensar = 110;
        dispensadors[1].angle_recollir = 25;
        dispensadors[1].pas = 1;
    }
}

static void actualitzarDispensador(EstatDispensador &d) {
    unsigned long ara = millis();
    switch (d.pas) {
        case 0: break;
        case 1:
            moureServo(d.canal, d.angle_dispensar);
            d.temps = ara;
            d.pas = 2;
            break;
        case 2:
            if (ara - d.temps >= MED_TEMPS_OBERT) {
                moureServo(d.canal, d.angle_recollir);
                d.temps = ara;
                d.pas = 3;
            }
            break;
        case 3:
            if (ara - d.temps >= MED_TEMPS_TANCAT) d.pas = 0;
            break;
    }
}

void actualitzarMedicacio() {
    actualitzarDispensador(dispensadors[0]);
    actualitzarDispensador(dispensadors[1]);
}

bool medicacioEnCurs() {
    return (dispensadors[0].pas != 0 || dispensadors[1].pas != 0);
}

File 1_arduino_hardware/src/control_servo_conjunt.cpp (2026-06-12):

#include "control_servo_conjunt.h"
#include <Wire.h>
#include <Adafruit_PWMServoDriver.h>

Adafruit_PWMServoDriver pwm = Adafruit_PWMServoDriver();

// ── Constants PCA9685 ─────────────────────────────────────────────────────────
#define SERVOMIN  150
#define SERVOMAX  590

#define CH_CELLA_DRET   0
#define CH_CELLA_ESQ    1
#define CH_ULL_DRET     2
#define CH_ULL_ESQ      3
#define CH_MED_REC1     4
#define CH_MED_REC2     5
#define CH_MED_CERCLE1  6
#define CH_MED_CERCLE2  7

// Angles per defecte (neutral)
#define ANGLE_CELLA_NEUTRAL  90
#define ANGLE_ULL_NEUTRAL    90
#define MED_OBERT           145
#define MED_TANCAT           60
#define MED_TEMPS_OBERT     1000  // ms comporta oberta
#define MED_TEMPS_TANCAT     800  // ms d'espera post-tancament

// ── Màquina d'estats genèrica per a dispensadors ─────────────────────────────
// Cada dispensador té el seu propi estat independent.
struct EstatDispensador {
    int  pas;             // 0=aturat, 1=obrint, 2=esperant_obert, 3=tancant, 4=espera_final
    unsigned long temps;  // millis() de l'últim canvi d'estat
    int  canal;           // canal PCA9685
};

static EstatDispensador dispensadors[4] = {
    {0, 0, CH_MED_REC1},
    {0, 0, CH_MED_REC2},
    {0, 0, CH_MED_CERCLE1},
    {0, 0, CH_MED_CERCLE2}
};

// ── Inicialització ────────────────────────────────────────────────────────────

void inicialitzarServos() {
    Wire.begin();
    pwm.begin();
    pwm.setPWMFreq(50);
    delay(10);

    // Posició neutral de partida
    moureServo(CH_CELLA_DRET,  ANGLE_CELLA_NEUTRAL);
    moureServo(CH_CELLA_ESQ,   ANGLE_CELLA_NEUTRAL);
    moureServo(CH_ULL_DRET,    ANGLE_ULL_NEUTRAL);
    moureServo(CH_ULL_ESQ,     ANGLE_ULL_NEUTRAL);
}

// ── Primitiva ─────────────────────────────────────────────────────────────────

void moureServo(int canal, int angle) {
    angle = constrain(angle, 0, 180);
    int pulse = map(angle, 0, 180, SERVOMIN, SERVOMAX);
    pwm.setPWM(canal, 0, pulse);
}

// ── Expressions ──────────────────────────────────────────────────────────────

void expressioNeutral() {
    moureServo(CH_CELLA_DRET, ANGLE_CELLA_NEUTRAL);
    moureServo(CH_CELLA_ESQ,  ANGLE_CELLA_NEUTRAL);
}

void expressioSorpresa() {
    moureServo(CH_CELLA_DRET, 80);
    moureServo(CH_CELLA_ESQ,   0);
}

void expressioEnfadat() {
    moureServo(CH_CELLA_DRET,  0);
    moureServo(CH_CELLA_ESQ,  80);
}

// ── Moviment per coordenades (enviat per la RPi) ──────────────────────────────
// La RPi envia angles ja calculats (pot incloure Filtre Kalman)

void movimentCelles(int angle_dret, int angle_esq) {
    moureServo(CH_CELLA_DRET, angle_dret);
    moureServo(CH_CELLA_ESQ,  angle_esq);
}

void movimentUlls(int angle_dret, int angle_esq) {
    moureServo(CH_ULL_DRET, angle_dret);
    moureServo(CH_ULL_ESQ,  angle_esq);
}

// ── Inici de seqüències de medicació ─────────────────────────────────────────

static void iniciarDispensador(int idx) {
    if (dispensadors[idx].pas == 0) {
        dispensadors[idx].pas = 1;
    }
}

void iniciarMedRec1()    { iniciarDispensador(0); }
void iniciarMedRec2()    { iniciarDispensador(1); }
void iniciarMedCercle1() { iniciarDispensador(2); }
void iniciarMedCercle2() { iniciarDispensador(3); }

// ── Motor de la màquina d'estats (cridar des de loop()) ───────────────────────

static void actualitzarDispensador(EstatDispensador &d) {
    unsigned long ara = millis();

    switch (d.pas) {
        case 0:
            // Aturat, res a fer
            break;

        case 1:
            // Obrim la comporta
            moureServo(d.canal, MED_OBERT);
            d.temps = ara;
            d.pas   = 2;
            break;

        case 2:
            // Esperem que la medicació caigui
            if (ara - d.temps >= MED_TEMPS_OBERT) {
                moureServo(d.canal, MED_TANCAT);
                d.temps = ara;
                d.pas   = 3;
            }
            break;

        case 3:
            // Esperem confirmació de tancament
            if (ara - d.temps >= MED_TEMPS_TANCAT) {
                d.pas = 0; // Seqüència completada
                // El care.ino enviarà "MED_OK" a la RPi en detectar pas==0
            }
            break;
    }
}

void actualitzarMedicacio() {
    for (int i = 0; i < 4; i++) {
        actualitzarDispensador(dispensadors[i]);
    }
}

bool medicacioEnCurs() {
    for (int i = 0; i < 4; i++) {
        if (dispensadors[i].pas != 0) return true;
    }
    return false;
}

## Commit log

2026-03-27 Add project skeleton
    Create initial repository structure: add .gitkeep placeholders for arduino_hardware, design_models, documentation, raspberry_brain/vision, raspberry_brain/voice, and web_cloud directories to preserve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
2026-03-27 folders rename and README
    Rename top-level project folders to numbered domain prefixes for clearer ordering: arduino_hardware -> 1_arduino_hardware, raspberry_brain -> 2_raspberry_brain, web_cloud -> 3_web_cloud, design_models -> 4_design_models; move related .gitkeep and main.py files accordingly. Update README to reflect the new /4_design_models path and adjust actuator description (replace Feetech feedback servo with Servo 360º). This clarifies repository structure and documentation for the monorepo.
2026-03-31 classe camera + estructura deteccio cares
2026-04-01 millora falsos positius amb detecció de ulls
2026-04-25 refactor de les classes
2026-05-10 moviment servo
2026-05-17 refactor control servos
2026-05-18 control motor
2026-05-19 controladora servos
2026-05-20 update control motors
2026-05-23 esquema motors i drivers
    [motors_drivers.fzz]
2026-05-23 esquema ultraso
    [motors_drivers.fzz, ultraso.fzz]
2026-05-24 esquema servos
    [motors_drivers.fzz, servos.fzz]
2026-05-24 encoders + millores codi
    [motors_drivers.fzz]
2026-05-30 canvis control servos
2026-06-06 Refactor Arduino drivers, add state machines
    Large refactor of Arduino hardware drivers and main sketch:
    - Encoders: made reads/resets atomic (noInterrupts), cleaned ISR/initialisation code and simplified attachInterrupt logic.
    - Motors: introduced Motor struct, inicialitzarMotor returns Motor; added smooth ramping (actualitzarMotor), direction helpers, emergency stop and motorAturat helper; removed old per-pin procedural API.
    - Servos: removed old Servo-based files and replaced with PCA9685-based control (control_servo_conjunt). Added initialization, primitives to move servos, facial expression helpers, coordinated cell/eye movements, and a non-blocking state machine to control 4 medicatio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
    [control_encoders.cpp, control_motor.cpp, control_servo_conjunt.cpp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]
2026-06-06 Refactor main.ino: non-blocking loop & safety
    Rework main.ino into a non-blocking, structured main loop with explicit subsystems and safety. Changes include: standardize pin defines, increase Serial baud to 115200, introduce Motor/Ultraso objects and encoder setup, initialize servos (PCA9685), and implement ramped motor control. Add heartbeat timeout and safe-stop behavior, obstacle detection from ultrasonic sensors, periodic telemetry (distances, encoders, mode) and MED completion notification. Enhance Serial command parser to support arguments (VEL, GIRA, ULLS, CELLES, EXP, RESET_ENC, HEARTBEAT) and limit input buffer. Split logic into clear functions: leer/processar comanda, verificarHear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
    [main.ino]
2026-06-11 Add hardware control modules and tests
    Introduce modular drivers and a test harness for Arduino hardware: adds encoder, motor, servo (PCA9685) and non-blocking ultrasonic modules (headers + implementations) for both main and test builds. Adds main config (9600) and test config (115200), renames main.ino → src/main/main.ino and injects debug Serial output and new collar command handling; comments out sensor/motor/telemetry calls. Replaces old test.ino with a comprehensive test/test.ino (includes FastLED) and duplicates updated drivers under src/test. Implements motor ramping, encoder ISRs, servo expressions and medicator state machine, and async ultrasonic state machine. Removes the legacy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
    [control_encoders.cpp, control_motor.cpp, control_servo_conjunt.cpp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]
2026-06-11 rename esquemes
    [CareE.fzz, motors_drivers.fzz, servos.fzz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]
